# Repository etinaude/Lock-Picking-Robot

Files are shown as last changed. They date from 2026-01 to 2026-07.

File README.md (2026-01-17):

# 🔑 Unlocked 🔑

## Introduction

media"

### Background

An open source Lock picking robot. Basically, there are many skeleton keys in use (the most common example is the TSA 007, [which is bad](https://www.youtube.com/watch?v=GhESSMvf_to)). Having one key which can open MANY different locks, especially without the lock owners people knowing it exists [or can be bought on Aliexpres for a pound](https://www.aliexpress.com/item/1005006407379398.html). It is a massive security issue. However, the TSA, locksmiths etc need to open locks in certain situations, and if you make locks easy to open for them, they are easy to open for everyone.

### 🔒 ➡️ 🔑🤖 ➡️ 🔓

So, lock-picking robot!!! The idea behind this robot is that it will be able to open difficult-to-pick locks. However, it takes a bit of time. That means you can get a lock which this robot would take 5 min to pick, but would require hundreds of keys (rather than a set of 7), and waiting with a very overt device by a lock for 5 min is a lot more obvious than unlocking it with a key which makes it look like you own the lock. 

### How it works

It feeds wire through a hollow key to press each pin and brute force all possible combinations. So security pins do not affect it since it is not looking for force feedback. However, more pins, or potential cut depths (entropy) make it take exponentially longer, it takes about 0.7s per combo so a 4 pin/4 cut depth lock would take about 3 min, but 5 pin/5 cut depth would take about 35 min to try all combos. So it's possible to design a lock with many security pins and an annoying keyway, very hard to pick for a human, but relatively quick for this robot.

### TLDR:

For lock sports/locksmiths its a fun toy, and for everyone else an interesting alternative to skeleton keys (and stop using TSA locks)

### Demo



## 💻 Software

### Prerequirements
- Arduino IDE
- Git
- Using [openrb board manager](https://raw.githubusercontent.com/ROBOTIS-GIT/OpenRB-150/master/package_openrb_index.json)
- Arduino SAMD Board Manager
- DYNAMIXEL2Arduino Library

Follow [this guide](https://emanual.robotis.com/docs/en/parts/controller/openrb-150/#development-environment) to get everything set up

The Source Code is in the repo, fully open source, if you make any changes (please do!) keep them open source as well (GPL 3.0 licence)

## ⚡ Electronics

### Components

- Servo Motors - [Dynamixel xl330-m288-t](https://emanual.robotis.com/docs/en/dxl/x/xl330-m288/) 
- Driver Board - [openrb-150](https://emanual.robotis.com/docs/en/parts/controller/openrb-150/)

## ⚙️ Mechanics

Unlocked uses FDM, SLA and DMLS parts for different levels of precision and strength, it uses 0.4mm copper wire to press the pins. More details in the `/3D files` Folder

### Tools Required

- FDM 3D printer
- Vat Polymerization 3D printer (DLP/SLA)
- (Ideally) DMLS 3D printer
- General Hand tools

## 📝 Notes

A new key blank will be needed for a different kind of lock based on the number of pins and the keyway, the current one can be modified to fit this, this should be made out of DMLS steel, companies like JLCPCB can print this, or you can use a SLA part which will likely break a few times so you'll a few spare.

### Future developments

- Include a more robust way to test if the lock is unlocked (for now it tilts slightly from gravity) but a current feedback servo would be better
- Use current feedback to create a set of possible sets or false sets to reduce the number of combos to try
- Before brute force try combing first

## 📄 References

- [Original 1991 Mechanical Patent -  US patent 5,172,578](https://www.researchgate.net/figure/S-A-Bitzioss-1991-design-for-a-Sputnik-decoder-pick-for-pin-tumbler-locks-US_fig9_271020041)
- [A good YouTube video of a design also based on the 1991 patent](https://www.youtube.com/watch?v=QE9MT1LG-PU)
- [Physical lock decoder](https://www.youtube.com/watch?v=CLcOZhq2GjQ)

## 💬 Contact Me

[https://etinaude.dev/contact](https://etinaude.dev/contact)

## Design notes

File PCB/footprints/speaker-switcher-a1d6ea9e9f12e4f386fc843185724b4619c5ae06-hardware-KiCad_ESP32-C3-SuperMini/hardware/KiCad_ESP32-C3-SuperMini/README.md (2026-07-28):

# ESP32 C3 SuperMini for KiCad

**WIP.** 3D model is not yet added, pin positions might be inaccurate (waiting for the actual part to arrive).

## Thanks to:

- [Ulf Hille](https://grabcad.com/library/esp32c3-supermini-1)

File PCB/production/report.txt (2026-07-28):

Placement file: '/home/etienne/Documents/git/Lock-Picking-Robot/PCB/unlocked-PCB/lock-picking-all-pos.csv'.
Info: Component count: 12.
Info: Done.

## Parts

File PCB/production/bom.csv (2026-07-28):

Designator | Footprint | Quantity | Value | LCSC Part #
C1, C2 | C0603 | 2 | CL10B104KB8NNNC-100nF | C1591
C3 | C0603 | 1 | CL10B223KB8NNNC-22nF | C21122
CN1, CN2, CN3 | CONN-TH_B2B-XH-A-LF-SN | 3 | B2B-XH-A | C158012
R1 | R0402 | 1 | ERA2AEB162X | C445601
U1 | ESP32-S3-SuperMini | 1 | ESP32-C3-SuperMini
U2 | HTSSOP-16_L5.0-W4.4-P0.65-LS6.4-BL-EP | 1 | DRV8876PWPR | C575551
U3 | VQFN-16_L3.0-W3.0-P0.50-BL-EP1.7 | 1 | MLX90393SLW-ABA-011-RE | C2649492
U4, U5 | CONN-TH_B4B-XH-A-LF-SN | 2 | B4B-XH-A | C144395

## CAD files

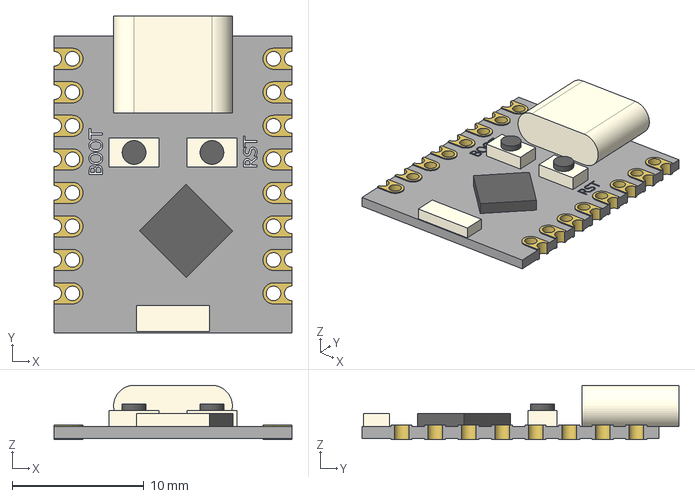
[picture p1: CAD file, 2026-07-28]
PCB/footprints/speaker-switcher-a1d6ea9e9f12e4f386fc843185724b4619c5ae06-hardware-KiCad_ESP32-C3-SuperMini/hardware/KiCad_ESP32-C3-SuperMini/ESP32-C3-SuperMini.stp
18.0 x 24.0 x 4.12 mm

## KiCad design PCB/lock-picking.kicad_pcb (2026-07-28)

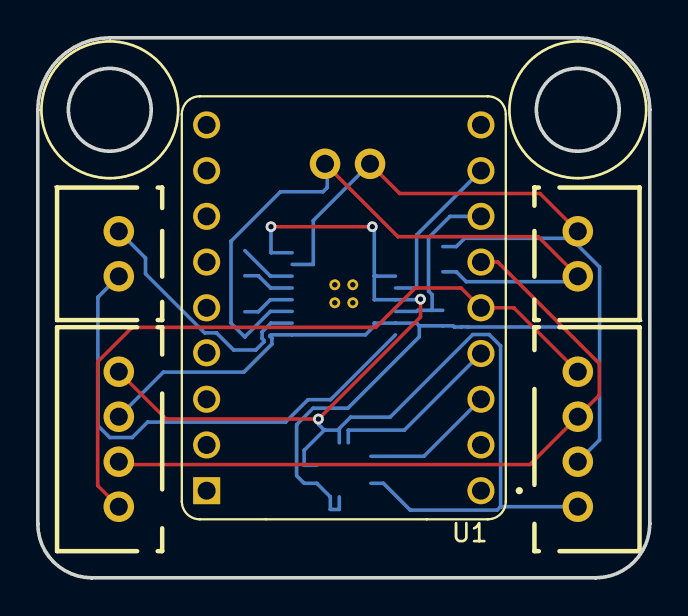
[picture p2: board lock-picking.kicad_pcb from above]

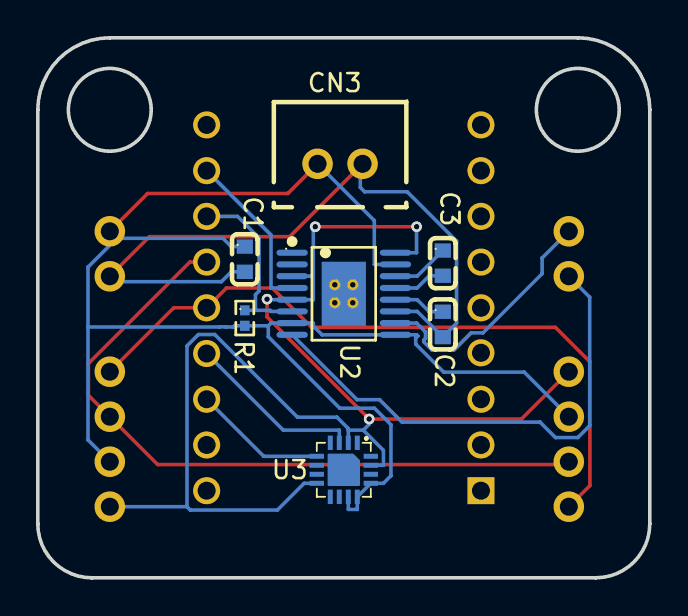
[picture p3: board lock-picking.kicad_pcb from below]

Board: 2 copper layers, 34.0 x 30.0 mm, 12 parts (7 on the bottom side), 14 nets.

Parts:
C1, C2: CL10B104KB8NNNC-100nF; C0603
C3: CL10B223KB8NNNC-22nF; C0603
CN1, CN2, CN3: B2B-XH-A; CONN-TH_B2B-XH-A-LF-SN
R1: ERA2AEB162X; R0402
U1: ESP32-C3-SuperMini; ESP32-S3-SuperMini
U2: DRV8876PWPR; HTSSOP-16_L5.0-W4.4-P0.65-LS6.4-BL-EP
U3: MLX90393SLW-ABA-011-RE; VQFN-16_L3.0-W3.0-P0.50-BL-EP1.7
U4, U5: B4B-XH-A; CONN-TH_B4B-XH-A-LF-SN

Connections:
unnamed: U2.3 (nSLEEP), U2.5 (VREF), U2.16 (PMODE), U3.2 (SENB/CS), U3.8 (VDD_IO), U3.15 (VDD), U4.1, U5.1
unnamed: C1.1, CN2.2, CN3.2, R1.2, U2.7 (IMODE), U2.9 (PGND), U2.15 (GND), U3.11 (A1), U3.12 (A0), U3.13 (VSS), U4.2, U5.2
unnamed: U1.1 (GPIO1), U3.5 (SDA/MOSI)
unnamed: U1.2 (GPIO2), U3.3 (SCL/SCLK)
unnamed: U1.3 (GPIO3), U4.4, U5.4
unnamed: U1.4 (GPIO4), U4.3, U5.3
unnamed: R1.1, U1.5 (GPIO5), U2.6 (IPROPI)
unnamed: U1.6 (GPIO6), U2.4 (nFAULT)
unnamed: C3.2, U2.13 (CPH)
unnamed: C3.1, U2.14 (CPL)
unnamed: CN1.2, U2.8 (OUT1)
unnamed: CN1.1, U2.10 (OUT2)
unnamed: C2.1, U2.12 (VCP)
unnamed: C1.2, C2.2, CN2.1, CN3.1, U2.11 (VM)

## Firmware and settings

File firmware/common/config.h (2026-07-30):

#include "structure.h"

#ifndef config_H
#define config_H

static ArmSettings arm1("00:11:22:33:44:55", 0.1, 0.01, 0.001, 1.0, 0.0, 0x10);

static ArmSettings *lookupTable[6] = {&arm1};

// ~~~ PINS ~~~
int PWM_PIN = 3;
int MAG_SDA_PIN = 21;
int MAG_SCL_PIN = 22;

int COMMS_SDA_PIN = 21;
int COMMS_SCL_PIN = 22;

#endif

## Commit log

2026-07-25 motor class
2026-07-28 PCB init
    [ESP32-C3-SuperMini.stp, bom.csv, designators.csv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]
2026-07-30 magnet sensor
2026-07-30 i2c receive
